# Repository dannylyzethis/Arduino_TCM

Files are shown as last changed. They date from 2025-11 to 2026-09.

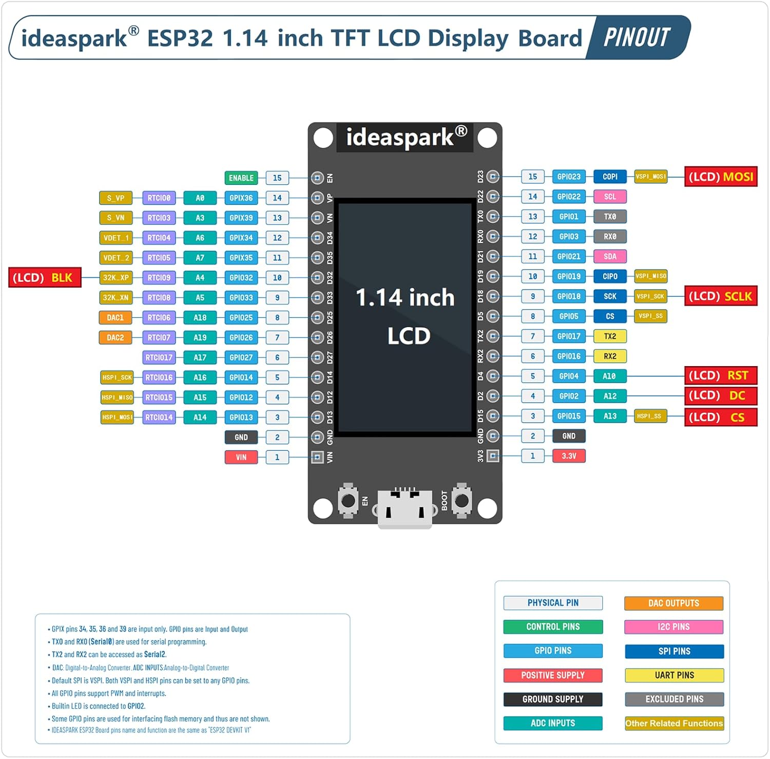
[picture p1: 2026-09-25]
hardware/references/ideaspark-pinout-source.jpg

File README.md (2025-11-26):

# Arduino TCM - Smart Home Climate Controller

Comprehensive home climate control system using ESP32 with:
- **Pellet Stove Control** (IR) - Automated temperature-based heat management
- **3 Ceiling Fans Control** (433MHz RF) - Independent fan speed and light control
- **Multi-Zone Temperature Monitoring** - DHT11 sensors with ESP-NOW wireless network
- **Temperature Equalization Learning** - AI learns to balance temps using fans
- **LCD Status Display** (Optional) - Real-time dashboard with all system status
- **Blynk IoT Integration** - Remote control from anywhere

## Features

### Pellet Stove Control (IR)
✅ **IR Learning Mode** - Capture commands from your pellet stove's remote
✅ **PID-Style Heat Control** - Automatically adjusts heat level (1-5) based on temperature
✅ **Manual Control** - Remote stove on/off and heat adjustment via Blynk app
✅ **Smart Heat Adjustment** - Uses 5 heat levels instead of on/off cycling
✅ **Adjustable Cooldown** - User-configurable interval (5-30 min) between auto adjustments
✅ **Heat Level Sync** - Manually sync software state with actual stove level

### Ceiling Fan Control (433MHz RF)
✅ **3 Independent Fans** - Control 3 separate ceiling fans
✅ **RF Learning Mode** - Capture commands from all 3 fan remotes
✅ **Speed Control** - Off, Low, Medium, High for each fan
✅ **Light Control** - Toggle lights on each fan
✅ **Persistent Storage** - RF codes saved to flash memory

### Temperature Equalization Learning
✅ **Automatic Learning** - System learns which fan affects which zone's temperature
✅ **Smart Fan Control** - Uses learned patterns to balance zone temperatures
✅ **Running Averages** - Collects up to 50 samples per fan/speed for accuracy
✅ **Auto-Equalization Mode** - Automatically balances temps when zones differ
✅ **Persistent Learning** - Learned patterns saved to flash memory

### General Features
✅ **Temperature & Humidity Monitoring** - Real-time DHT11 sensor readings
✅ **Multi-Zone Control** - Control stove based on temperature from different rooms
✅ **ESP-NOW Communication** - Fast, reliable wireless sensor network (no internet needed)
✅ **LCD Status Display** - Optional 135x240 color display shows all system status
✅ **Real-time Status** - Monitor all devices from anywhere via Blynk
✅ **Sensor Protection** - Auto-disables if temperature sensor fails
✅ **Unified Control** - Single Blynk app controls stove, fans, and monitors temperature

## Hardware Requirements

### Core Components
- **ESP32 development board**
- **DHT11** temperature and humidity sensor
- Jumper wires
- Breadboard

### For Pellet Stove Control (IR)
- **VS1838B** IR receiver module (38kHz)
- **940nm IR LED** transmitter
- **2N2222 NPN transistor** (for IR LED)
- **100Ω resistor** (for IR LED current limiting)
- **10kΩ resistor** (for transistor base)

### For Ceiling Fan Control (RF)
- **433MHz RF Transmitter Module** (FS1000A, SYN115, or RXB6)
- **433MHz RF Receiver Module** (Optional, for learning mode - RXB6 or WL101-341)
- **17cm wire antenna** (Optional, for better range)

### For LCD Display (Optional)
- **ST7789 LCD Display** (135x240 pixels) - Real-time status dashboard
- Display shows temperatures, fan status, heat level, learning progress

### Optional
- **Additional ESP32** with DHT11 for remote zone temperature monitoring
- Enclosure/case for permanent installation
- Power supply (USB or 5V adapter)

## Wiring Diagram

### DHT11 Temperature Sensor
```
DHT11          ESP32
─────────────────────
VCC     →      3.3V
GND     →      GND
DATA    →      GPIO13
```

### VS1838B IR Receiver
```
VS1838B        ESP32
─────────────────────
VCC     →      3.3V
GND     →      GND
OUT     →      GPIO14
```

### IR LED Transmitter Circuit
```
ESP32 GPIO5 ──┬─── 10kΩ ───┬─── Transistor Base (2N2222)
              │             │
             GND           Emitter → GND
                            │
                         Collector
                            │
                            ├─── IR LED Anode (+)
                            │
                          100Ω
                            │
                         5V/VIN

IR LED Cathode (-) → Transistor Collector
```

**Important Notes:**
- IR LED must be connected through a transistor (ESP32 GPIO can't provide enough current)
- Use 100Ω resistor to limit IR LED current (~40-50mA)
- Point IR LED directly at your pellet stove's IR receiver

### 433MHz RF Transmitter (Required for Fan Control)
```
RF TX Module   ESP32
─────────────────────
VCC     →      5V (or 3.3V depending on module)
GND     →      GND
DATA    →      GPIO16
ANT     →      17cm wire antenna (optional, for better range)
```

### 433MHz RF Receiver (Optional, for Learning Mode)
```
RF RX Module   ESP32
─────────────────────
VCC     →      5V (or 3.3V depending on module)
GND     →      GND
DATA    →      GPIO17
ANT     →      17cm wire antenna (optional, for better range)
```

**Important Notes:**
- Most RF modules work with both 3.3V and 5V, check your module's datasheet
- 17cm antenna wire significantly improves range (cut to exactly 17.3cm for 433MHz)
- RF transmitter is REQUIRED to control ceiling fans
- RF receiver is OPTIONAL - only needed for learning mode to capture fan remote codes
- If you already know your fan RF codes, you can skip the receiver and enter codes manually
- Point RF transmitter toward ceiling fans (RF works through walls, no line-of-sight needed)
- Typical range: 30-50 feet without antenna, 100+ feet with antenna

### ST7789 LCD Display (Optional, 135x240 pixels)
```
ST7789 LCD     ESP32
─────────────────────
VCC     →      3.3V
GND     →      GND
SCL     →      GPIO18 (SPI Clock / SCLK)
SDA     →      GPIO23 (SPI MOSI)
CS      →      GPIO15 (Chip Select)
DC      →      GPIO2  (Data/Command)
RST     →      GPIO4  (Reset)
BLK     →      GPIO32 (Backlight control)
```

**Display Features:**
- **Real-time Dashboard** - Updates every 2 seconds
- **Zone Temperatures** - Shows both Zone 1 and Zone 2 temperatures
- **Humidity Display** - Real-time humidity percentage
- **Heat Level Indicator** - Visual bar graph (1-5 blocks)
- **Fan Status** - Shows all 3 fans (OFF/LOW/MED/HI)
- **Learning Progress** - Total learning samples collected
- **Auto-Equalization Status** - Shows if auto-EQ is active
- **Temperature Difference** - Shows zone temp difference
- **WiFi/Blynk Status** - Connection indicators
- **Auto Mode Indicator** - Shows AUTO or MAN mode
- **Stove Status** - Shows ON/OFF state

**Display Layout (240x135 Landscape):**
```
┌────────────────────────────────────┐
│ STOVE CTRL          W B AUTO       │
│ Z1:72.5F  H:45%  Tgt:70F           │
│ Z2:70.2F  Heat:▓▓▓░░ ON            │
│ ────────────────────────            │
│ F1:HI  F2:OFF  F3:MED               │
│ Learn:23  AutoEQ:ON                 │
│ Diff:2.3F  Zone:1                   │
└────────────────────────────────────┘
```

## Software Requirements

### Arduino IDE Setup

1. Install [Arduino IDE](https://www.arduino.cc/en/software) (1.8.19 or later)
2. Add ESP32 board support:
   - Go to **File → Preferences**
   - Add to **Additional Board Manager URLs**:
     `https://dl.espressif.com/dl/package_esp32_index.json`
   - Go to **Tools → Board → Boards Manager**
   - Search for "ESP32" and install **"esp32 by Espressif Systems"**

### Required Libraries

Install via Arduino IDE (**Sketch → Include Library → Manage Libraries**):

| Library | Author | Purpose |
|---|---|---|
| **Blynk** | Volodymyr Shymanskyy | IoT platform connectivity |
| **DHT sensor library** | Adafruit | DHT11 temperature/humidity |
| **Adafruit Unified Sensor** | Adafruit | DHT library dependency |
| **IRremoteESP8266** | David Conran, Sebastien Warin | IR transmit/receive (pellet stove) |
| **rc-switch** | sui77 | 433MHz RF transmit/receive (ceiling fans) |
| **Adafruit GFX Library** | Adafruit | Graphics core for LCD (optional) |
| **Adafruit ST7789** | Adafruit | ST7789 LCD display driver (optional) |

## Blynk Setup

### 1. Create Blynk Project

1. Download [Blynk app](https://blynk.io/) (iOS/Android) or use [Blynk.Console](https://blynk.cloud/)
2. Create a new **Template** or **Project**
3. Note your **Template ID** and **Auth Token**

### 2. Add Datastreams

Configure these virtual pins in your Blynk template:

| Pin | Name | Type | Range | Purpose |
|-----|---|---|---|---|
| **V0** | Temperature | Value | 32-120°F | Current temperature display |
| **V2** | Humidity | Value | 0-100% | Current humidity display |
| **V3** | Stove ON | Button | 0-1 | Turn stove on |
| **V4** | Stove OFF | Button | 0-1 | Turn stove off |
| **V5** | Target Temp | Slider | 60-80°F | Temperature setpoint |
| **V6** | Auto Mode | Switch | 0-1 | Enable heat auto-adjustment |
| **V7** | Learn IR | Button | 0-1 | Enter learning mode |
| **V8** | Heat UP | Button | 0-1 | Manual heat increase |
| **V9** | Heat DOWN | Button | 0-1 | Manual heat decrease |
| **V10** | Heat Level | Value | 0-5 | Current heat level display |
| **V11** | Stove Status | LED/Value | 0-1 | Stove on/off indicator |
| **V12** | Cooldown Period | Slider | 5-30 min | Auto adjustment interval |
| **V13** | Heat Sync | Slider | 0-5 | Manual heat level sync |
| **V14** | Zone Select | Menu | 0-2 | Select active zone (0=Zone1, 1=Zone2, 2=Avg) |
| **V15** | Zone 2 Temp | Value | 32-120°F | Remote sensor temperature |

### 3. Add Dashboard Widgets

**Recommended Dashboard Layout:**
- **Gauge** widget → V0 (Temperature in °F)
- **Gauge** widget → V2 (Humidity %)
- **Button** widget → V3 (Stove ON)
- **Button** widget → V4 (Stove OFF)
- **Slider** widget → V5 (Target Temperature: 60-80°F)
- **Switch** widget → V6 (Auto Mode)
- **Button** widget → V7 (Learn IR Codes)
- **Button** widget → V8 (Heat UP ↑)
- **Button** widget → V9 (Heat DOWN ↓)
- **Value Display** widget → V10 (Heat Level: 0-5)
- **LED** widget → V11 (Stove Status: On/Off)
- **Slider** widget → V12 (Cooldown Period: 5-30 minutes)
- **Slider** widget → V13 (Heat Level Sync: 0-5)
- **Menu** widget → V14 (Zone Select: Zone 1, Zone 2, Average)
- **Value Display** widget → V15 (Zone 2 Temperature)

## Configuration

### Update Credentials

Edit `Arduino_TCM_Blynk_DHT11.ino` with your details:

```cpp
// Blynk credentials
#define BLYNK_TEMPLATE_ID "YOUR_TEMPLATE_ID"
char auth[] = "YOUR_AUTH_TOKEN";

// WiFi credentials
char ssid[] = "YOUR_WIFI_SSID";
char pass[] = "YOUR_WIFI_PASSWORD";
```

### Adjust Pin Assignments (if needed)

```cpp
#define DHTPIN 4        // DHT11 sensor data pin
#define IR_RECV_PIN 14  // IR receiver output
#define IR_SEND_PIN 15  // IR LED control pin
```

### Set Temperature Preferences

```cpp
float tempSetpoint = 70.0;          // Default target temperature (°F)
float tempHysteresis = 2.0;         // Temperature buffer for heat adjustments
unsigned long adjustmentCooldown = 900000; // 15 minutes between adjustments (ms)
```

**How PID-Style Control Works:**
- Stove stays **ON** (you control on/off manually)
- Heat level **increases** when temp < `setpoint - 2°F` (e.g., < 68°F)
- Heat level **decreases** when temp > `setpoint + 2°F` (e.g., > 72°F)
- Adjustments happen at configurable intervals (default: 15 minutes)
- Cooldown period can be adjusted via Blynk slider (5-30 minutes)
- Heat levels range from 1 (minimum) to 5 (maximum)

## Installation & Setup

### Step 1: Upload Code

1. Open `Arduino_TCM_Blynk_DHT11/Arduino_TCM_Blynk_DHT11.ino` in Arduino IDE
2. Update credentials (see Configuration section)
3. Select board: **Tools → Board → ESP32 Arduino → ESP32 Dev Module**
4. Select COM port: **Tools → Port → (your port)**
5. Click **Upload** ⬆️
6. Open **Serial Monitor** (115200 baud) to verify connection

### Step 2: Learn IR Codes

**You must teach the system your pellet stove's remote commands:**

1. In **Blynk app**, tap the **"Learn IR"** button (V7)
2. Watch the **Serial Monitor** for instructions
3. When prompted, press these buttons on your **pellet stove remote**:
   - **POWER ON** button (point remote at VS1838B receiver)
   - Wait for confirmation ✓
   - **POWER OFF** button
   - Wait for confirmation ✓
   - **HEAT UP** button
   - Wait for confirmation ✓
   - **HEAT DOWN** button
   - Wait for confirmation ✓

4. Serial Monitor will display captured codes:
   ```
   === IR CODES SAVED ===
   Power ON: 0x1234ABCD
   Power OFF: 0x5678EF01
   Heat Up: 0x9ABC2345
   Heat Down: 0xDEF67890
   Learning mode complete!
   ```

5. **Codes are automatically saved to flash memory!**
   - IR codes persist through power cycles and reboots
   - No need to re-learn codes after restarting
   - Codes are loaded automatically on startup

**Note:** If you want to re-learn codes, just press the "Learn IR" button again - new codes will overwrite the old ones.

### Step 3: Test Manual Control

1. In Blynk app, tap **"Stove ON"** button (V3)
2. Watch your pellet stove turn on (starts at heat level 3)
3. Check **Stove Status** LED (V11) turns on
4. Check **Heat Level** display (V10) shows "3"
5. Test **Heat UP** (V8) and **Heat DOWN** (V9) buttons
6. Verify heat level changes (should range 1-5)
7. Test **"Stove OFF"** button (V4) to turn off

### Step 4: Enable Heat Automation

1. **Turn stove ON** manually using V3 button
2. Set desired **Target Temperature** using slider (V5) - e.g., 70°F
3. **Optional:** Adjust **Cooldown Period** slider (V12) - default is 15 minutes
4. Enable **Auto Mode** switch (V6)
5. System will automatically adjust heat level at your chosen interval:
   - **Increase heat** when temp < 68°F (up to level 5)
   - **Decrease heat** when temp > 72°F (down to level 1)
   - **Maintain** heat level when temp is 68-72°F

### Step 5: Sync Heat Level (If Needed)

If the system's heat level gets out of sync with your actual stove (e.g., after a reboot or manual remote changes):

1. Check your stove's actual heat level (look at the display)
2. Use **Heat Sync slider** (V13) to set the correct level (0-5)
3. System now knows the true stove state
4. Auto mode will work correctly from this point

**When to use:**
- After ESP32 reboots while stove is running
- If you manually changed heat using the physical remote
- If an IR command failed and states are mismatched

### Step 6: Setup Multi-Zone Control (Optional)

Control your pellet stove based on temperature from a different room using ESP-NOW wireless communication.

**What You Need:**
- Second ESP32 board
- DHT11 sensor for remote room
- 5V power supply for remote sensor

**Setup Instructions:**

1. **Get Main Controller's MAC Address**
   - Upload main sketch to primary ESP32
   - Open Serial Monitor (115200 baud)
   - Look for MAC address in WiFi connection messages
   - Note it down (format: XX:XX:XX:XX:XX:XX)

2. **Program Remote Sensor**
   - Open `Remote_Sensor_ESP32/Remote_Sensor_ESP32.ino`
   - Replace `mainControllerMAC[]` with your main controller's MAC
   - Update WiFi credentials (must match main controller)
   - Upload to second ESP32

3. **Wire Remote Sensor**
   ```
   DHT11          ESP32
   ─────────────────────
   VCC     →      3.3V
   GND     →      GND
   DATA    →      GPIO4
   ```

4. **Place Remote Sensor**
   - Install in room you want to monitor
   - Must be within WiFi range of main controller
   - Sends temperature every 30 seconds

5. **Configure Zone in Blynk App**
   - Use **Zone Select menu** (V14):
     - **Zone 1** - Control based on stove room temp (local sensor)
     - **Zone 2** - Control based on remote room temp
     - **Average** - Use average of both rooms
   - View **Zone 2 Temp** (V15) to verify remote sensor is working

**How It Works:**
- Remote sensor sends temp via ESP-NOW (no internet needed)
- Main controller receives and displays on V15
- Select which zone controls the stove via V14
- Auto mode adjusts heat based on selected zone

**Troubleshooting:**
- If Zone 2 shows 0°F → Check MAC address configuration
- If "Remote sensor offline" → Check WiFi connection and range
- System automatically falls back to Zone 1 if remote fails

## Usage

### Manual Mode (Default)
- Use **Stove ON** (V3) and **Stove OFF** (V4) buttons to control power
- Use **Heat UP** (V8) and **Heat DOWN** (V9) to manually adjust heat (1-5)
- Monitor temperature, humidity, and current heat level in real-time
- Full manual control without any automation

### Auto Mode (Smart Heat Adjustment)
1. **Turn stove ON** manually first (V3)
2. Set target temperature with slider (V5)
3. Adjust cooldown period with slider (V12) - default 15 min, range 5-30 min
4. Enable Auto Mode switch (V6)
5. System automatically adjusts heat level at your chosen interval:
   - Too cold → Increases heat (up to level 5)
   - Too hot → Decreases heat (down to level 1)
   - Just right → Maintains current heat level
6. Can adjust cooldown period anytime (even while auto mode is running)
7. Can still manually adjust heat or turn off stove anytime
8. Auto mode disables when you turn stove OFF

### Monitoring
- **Temperature** updates every 2 minutes
- **Humidity** updates every 2 minutes
- **Heat level** (1-5) displays current setting
- **Stove status** LED shows on/off state
- Serial Monitor provides detailed automation logs

## How It Works

### PID-Style Heat Level Control

Unlike simple on/off thermostats, this system uses **proportional control** by adjusting heat levels:

```
Current Temp < Target - 2°F  →  Increase heat level (1→2→3→4→5)
Current Temp > Target + 2°F  →  Decrease heat level (5→4→3→2→1)
Within ±2°F of target       →  Maintain current heat level
```

**Example (Target = 70°F, Cooldown = 15 min):**
- Room at 65°F, Heat Level 2 → **Increases to Level 3** (15 min later)
- Room at 67°F, Heat Level 3 → **Increases to Level 4** (15 min later)
- Room at 69°F, Heat Level 4 → **Maintains Level 4** (in range)
- Room reaches 72°F → **Decreases to Level 3** (15 min later)
- System continuously adjusts to maintain comfort

**Why This is Better:**
- Pellet stoves are designed for continuous operation, not on/off cycling
- Smoother temperature control without temperature swings
- More efficient fuel usage
- Extends stove lifespan (less wear from start/stop cycles)

### Safety Features

- **Manual on/off control** - You control when stove turns on/off (not automated)
- **Sensor failure protection** - Auto mode disables after 3 consecutive sensor failures
- **IR code validation** - Won't send commands if codes not learned
- **Heat level limits** - Won't exceed min (1) or max (5) settings
- **Adjustable cooldown** - User-configurable intervals (5-30 min) prevent command spam
- **Manual override** - Can disable auto mode or adjust heat anytime
- **Auto-disable on OFF** - Auto mode turns off when stove is manually shut off
- **Persistent storage** - IR codes survive power outages and reboots

## Troubleshooting

### DHT11 Sensor Issues

**Symptom:** "Failed to read from DHT sensor!"

**Solutions:**
- ✓ Check wiring (VCC, GND, DATA)
- ✓ Ensure sensor has power (3.3V or 5V)
- ✓ Verify `DHTPIN` matches GPIO4
- ✓ Try adding 10kΩ pull-up resistor on data line

### IR Learning Fails

**Symptom:** No codes captured / "IR Signal Received!" not appearing

**Solutions:**
- ✓ Check VS1838B wiring (VCC, GND, OUT)
- ✓ Point remote **directly** at receiver (2-6 inches away)
- ✓ Replace remote batteries
- ✓ Verify receiver pin is GPIO14
- ✓ Check Serial Monitor is open (115200 baud)

### IR Commands Not Working

**Symptom:** Stove doesn't respond to commands

**Solutions:**
- ✓ Check IR LED wiring and transistor circuit
- ✓ Verify 100Ω resistor in series with IR LED
- ✓ Point IR LED directly at stove's receiver
- ✓ Reduce distance (try 1-3 feet initially)
- ✓ Check LED polarity (long leg = anode/+)
- ✓ Some stoves use different protocols - try adjusting:
  ```cpp
  irsend.sendNEC(code, 32);  // Try: sendSony, sendRC5, sendSamsung
  ```

### WiFi Connection Issues

**Symptom:** Can't connect to WiFi

**Solutions:**
- ✓ Verify SSID and password are correct
- ✓ ESP32 only supports **2.4GHz** networks (not 5GHz)
- ✓ Check WiFi signal strength
- ✓ Restart router if necessary

### Blynk Connection Issues

**Symptom:** "Not connected to Blynk"

**Solutions:**
- ✓ Verify Auth Token is correct (copy from Blynk.Console)
- ✓ Check Template ID matches
- ✓ Ensure virtual pins match datastream configuration
- ✓ Check Blynk server status at [status.blynk.cc](https://status.blynk.cc)

### Automation Not Adjusting Heat

**Symptom:** Auto mode enabled but heat level doesn't change

**Solutions:**
- ✓ **Stove must be ON** - Auto mode only works when stove is running
- ✓ Verify IR codes were learned successfully (Power, Heat Up, Heat Down)
- ✓ Check temperature is outside hysteresis range (±2°F)
- ✓ **Wait for cooldown period** - default is 15 minutes between adjustments
- ✓ Check Cooldown Period slider (V12) - may be set too high
- ✓ Ensure Auto Mode switch (V6) is ON
- ✓ Monitor Serial output for automation messages
- ✓ Check Heat Level display (V10) - should be 1-5
- ✓ Manually test Heat UP/DOWN buttons first
- ✓ If at max heat (5) and still cold, system won't increase further
- ✓ If at min heat (1) and still hot, system won't decrease further

## Advanced Customization

### Change Update Frequency

```cpp
// Default: 2 minutes (120,000 ms)
timer.setInterval(120000L, sendData);

// Change to 1 minute:
timer.setInterval(60000L, sendData);
```

### Adjust Temperature Control Parameters

```cpp
// Default: ±2°F buffer before adjusting heat
float tempHysteresis = 2.0;

// Tighter control (±1°F) - more frequent adjustments:
float tempHysteresis = 1.0;

// Wider buffer (±3°F) - less frequent adjustments:
float tempHysteresis = 3.0;

// Adjustment cooldown (default: 15 minutes)
unsigned long adjustmentCooldown = 900000; // milliseconds

// Note: Cooldown can also be adjusted via Blynk slider (V12)
// Range: 5-30 minutes (300000-1800000 ms)
```

**Recommended Cooldown Settings:**
- **5-10 minutes** - Quick response, smaller spaces, well-insulated
- **15 minutes** - Default, balanced for most pellet stoves
- **20-30 minutes** - Conservative, larger spaces, slow-response stoves

### Add More IR Commands

```cpp
// In setup, learn additional buttons:
uint64_t irCode_FanSpeed = 0;
uint64_t irCode_Timer = 0;

// Create new Blynk handlers:
BLYNK_WRITE(V8) {
  if (param.asInt() == 1) {
    sendIRCommand(irCode_FanSpeed);
  }
}
```

### Change IR Protocol

If your stove uses a different IR protocol, modify:

```cpp
// Line 70 - Change from NEC to your protocol:
irsend.sendSony(code, 12);      // Sony 12-bit
// or
irsend.sendRC5(code, 13);       // RC5
// or
irsend.sendSamsung(code, 32);   // Samsung
```

## Safety Disclaimer

⚠️ **IMPORTANT SAFETY INFORMATION** ⚠️

This is an automation project for educational purposes. When using with heating appliances:

- **Never leave automated stove unattended for extended periods**
- **Install smoke detectors and CO detectors near stove**
- **Ensure stove has proper clearances from combustible materials**
- **Follow all manufacturer safety guidelines**
- **Use at your own risk** - author assumes no liability
- **Test thoroughly** before relying on automation
- **Manual override should always be accessible**

## Project Structure

```
Arduino_TCM/
├── Arduino_TCM_Blynk_DHT11/
│   └── Arduino_TCM_Blynk_DHT11.ino    # Main controller sketch
├── Remote_Sensor_ESP32/
│   └── Remote_Sensor_ESP32.ino        # Remote zone sensor (optional)
└── README.md                           # This file
```

## Future Enhancements

Potential additions (contributions welcome!):
- [ ] EEPROM storage for learned IR codes (persist across reboots)
- [ ] Weekly temperature schedule
- [ ] Multiple temperature zones
- [ ] Push notifications (low temp alerts)
- [ ] Historical data logging
- [ ] Web dashboard
- [ ] Voice control integration (Alexa/Google Home)

## License

Open source - MIT License. Free to modify and use for personal projects.

## Support

For issues or questions:
- Check troubleshooting section above
- Review serial monitor output for debugging
- Verify all wiring matches diagrams
- Test components individually

---

**Built with:** ESP32 | DHT11 | VS1838B | IR LED | Blynk IoT
**Author:** Arduino TCM Project
**Version:** 2.1 (PID-style heat level control)

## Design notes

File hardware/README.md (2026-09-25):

# Arduino TCM board design — Rev A planning

Status: native KiCad electrical draft created; physical socket and RF details remain unverified. No PCB or fabrication files.
Firmware baseline: commit 651ab30, Arduino_TCM_Blynk_DHT11.ino.

Circuit work: see [shared node circuit draft](node-circuit-draft.md) and `node-circuit-model.json` for proposed component values, connectivity, GPIO assignments and stove/fan assembly variants. These supersede the early connector concepts below. Native schematic: `tcm_node_rev_a_draft.kicad_sch`; project: `tcm_node_rev_a_draft.kicad_pro`. The repository now resides in C:/Projects/Arduino_TCM. Initial ERC passed with zero errors and warnings; the exported connections matched the design model. See preview/ for SVG and PNG views. This does not validate real hardware compatibility.

## Scope and decisions

Accepted architecture: one ELECROW CrowPanel Basic 7-inch dashboard/coordinator, one independent stove-control node, and three fan nodes. Five ESP32 devices total. The user selected independent stove control so a dashboard restart or update does not itself stop the stove node's local control loop. Fan nodes transmit RF commands; the stove node transmits IR commands. No wired appliance-power switching is required.

Working PCB direction: one common carrier PCB with different component population for stove and fan roles. Plug-in ESP32 development boards remain the working preference; exact model and mechanical fit are pending. The CrowPanel already includes its own ESP32 and does not require this carrier to operate its display.

| Role | Quantity | Planned peripherals |
| --- | ---: | --- |
| CrowPanel dashboard | 1 | Built-in display/touch and ESP32; user settings, zone overview and wireless coordination |
| Stove node | 1 | Local temperature sensor, IR emitter/receiver; independent local control |
| Fan node | 3 | Local temperature sensor, RF transmitter, optional RF learning receiver; wireless command/telemetry link |

The existing firmware transmits all fan commands from the main controller, and the remote sketch is a sensor node. Distributed fan control therefore requires firmware changes: addressed commands, node registration, acknowledgements, duplicate suppression, freshness limits, local code storage and explicit lost-link behavior. ESP-NOW is the provisional inter-board transport because the repository already uses it. Channel coordination with the main controller's Wi-Fi connection must be designed and tested.

An acknowledgement from a fan node confirms command handling/transmission, not physical fan operation. RF toggle commands, especially light toggles, must not be re-executed on network retries. Keep desired state and last transmitted state distinct from any independently confirmed state.

RF frequency, modulation and protocol are unverified. The repository assumes 433 MHz and uses RCSwitch; do not select a production RF module from that assumption alone. Obtain each remote's model/FCC ID or manufacturer documentation and verify capture/replay compatibility. Nearby placement does not isolate fans that share the same RF address; pairing/address behavior must also be tested.

Exact node ESP32 and RF module models, sensor choice, input supply, enclosure dimensions and assembly preference must be selected before footprints and board outline are finalized. Do not assume different ESP32 development boards share header spacing or pin order. Confirm the CrowPanel model and PCB revision against ELECROW documentation before firmware bring-up; the Amazon listing title alone does not establish the revision.

## Control responsibilities

### Node board candidate and power decision

All four custom nodes will use USB wall adapters (confirmed by user). The nominated plug-in board is the ideaspark ESP32 development board with integrated 1.14-inch ST7789 135x240 display, CH340 USB serial, USB-C and soldered headers, as described in the user's listing title. Treat it as the current candidate, pending verified header pinout, row spacing, outline, underside clearance and power schematic. Do not substitute a generic ESP32 DevKit footprint.

The local display can show node identity, temperature, connection health and last transmitted command. The existing repository already targets an ST7789 at this resolution, but this does not establish electrical compatibility or successful operation on the candidate board. Preserve integrated display wiring; any earlier suggestion to move LCD CS/DC applies only to separately wired displays, not fixed PCB connections. Reserve firmware LCD GPIOs 23, 18, 15, 2, 4 and 32 provisionally until the actual board pinout is verified.

Keep the USB connector and screen accessible when placing the carrier sockets. Determine how peripheral power is drawn from USB without overloading the onboard regulator or creating a second power path. RF module supply and connector remain unresolved until remote identification; leave the RF module interface modular in the architecture, not a finalized footprint.

Candidate listing supplied by user: https://a.co/d/050E23FP . No mechanical drawing or manufacturer schematic has yet been verified.

### Firmware ownership

- Dashboard: present room measurements and node health, send settings and manual requests, coordinate fan behavior, and optionally provide the Blynk bridge.
- Stove node: own IR timing, learned codes, heat-adjustment cooldown and the local control loop. Dashboard requests pass through the node's control logic. Define startup behavior, sensor-fault behavior and loss of remote-temperature data before enabling automation.
- Fan nodes: own RF transmission and learned codes; report local temperature and command acknowledgements. Define loss-of-link behavior explicitly rather than assuming an automatic off command is appropriate.
- All nodes: report measurement age, fault state and last applied command ID. Reject stale requests and suppress duplicate actions. A screen restart must not replay an old power/light toggle.
- Autonomous stove operation is a design objective, not a claim of implemented behavior. Persistence, restart handling and fallback from a stale remote zone still require implementation and bench validation.

## Functional architecture

```mermaid
flowchart LR
  H[CrowPanel dashboard / coordinator] <-. Proposed ESP-NOW link .-> S[Independent stove node]
  H <-. Proposed ESP-NOW link .-> N[Fan nodes x3]
  ST[Stove-zone temperature sensor] --> S
  IR[IR learning receiver] --> S
  S --> DRIVER[IR LED driver and emitter]
  DRIVER -. IR commands .-> STOVE[Pellet stove]
  T[Local temperature sensor per node] --> N
  N --> TX[RF transmitter per node]
  RX[Optional RF learning receiver per node] --> N
  TX -. Fan remote protocol .-> F[Respective ceiling fan]
```

## Firmware pin inventory

These are GPIO numbers, not module pad numbers or development-board header positions. This inventory describes the existing centralized firmware; the fan-node pin map remains to be finalized.

| Function | Existing GPIO | Board-design consideration |
| --- | ---: | --- |
| DHT data | 13 | Pull-up to the selected sensor-compatible logic rail; verify exact sensor supply specification |
| IR receiver output | 14 | Verify receiver supply, output levels and physical pin order |
| IR transmitter control | 5 | Boot-strapping pin; proposed reassignment to GPIO25 if the chosen ESP32 supports it |
| RF transmitter data | 16 | Confirm availability on exact ESP32 variant and transmitter input threshold |
| RF receiver data | 17 | Confirm availability and receiver output voltage; translate levels if needed |
| LCD MOSI | 23 | Verify display connector pin order |
| LCD SCLK | 18 | Keep SPI connections short |
| LCD CS | 15 | Preserve integrated display wiring; do not load with carrier circuitry |
| LCD DC | 2 | Preserve integrated display wiring; do not load with carrier circuitry |
| LCD reset | 4 | Retain provisionally |
| LCD backlight enable | 32 | Verify whether module pin is a logic input or requires a current driver |

The proposed changes apply provisionally to a classic ESP32 with those pins available. They have not been applied to firmware. GPIO16/17 availability must be checked against the chosen module, including any PSRAM usage.

## Proposed connector functions

Pin order and connector part numbers are intentionally pending the actual hardware.

| Reference | Interface | Signals / requirements |
| --- | --- | --- |
| J1 | Power input | Supply and ground; input voltage and connector TBD |
| J2 | Local sensor | Sensor supply, ground, DHT data; short external cable allows separation from board heat |
| J3 | IR emitter | Current-limited LED supply and switched return; polarity marked |
| J4 | IR receiver | Selected receiver supply, ground, data |
| J5 | RF transmitter | Selected module supply, ground, data; antenna arrangement per module |
| J6 | RF receiver | Selected module supply, ground, level-compatible data |
| J7 | Reserved | No separate LCD connector required; display is on the CrowPanel |
| J8 | Programming/service | Defined after MCU choice; integrated module needs UART/reset/boot provision |

## Electrical work before schematic freeze

- Build separate power budgets for the CrowPanel and each node, covering radio transients and RF/IR loads. Espressif specifies at least 500 mA supply capability for the classic ESP32 itself; this is not a complete node budget. All four nodes use USB wall adapters; exact adapter rating and available peripheral current remain to be verified.
- If using a development board, verify its regulator capacity and USB/external-power path. Prevent backfeeding when programming with another supply attached.
- If using an integrated module, implement its specified supply decoupling, enable/reset timing, boot control, programming interface and antenna keepout.
- Correct the README's ambiguous IR circuit: supply -> current-limiting resistor -> LED anode; LED cathode -> transistor collector/drain; emitter/source -> ground. Select a transistor driven correctly at 3.3 V, a default-off control network, and resistor ratings from the actual LED pulse limits and duty cycle. Do not copy the existing drawing or its resistor values without calculation.
- Verify every peripheral's supply and logic limits. A module powered at 5 V must not automatically be treated as safe for a 3.3 V ESP32 input.
- Verify sensor voltage requirements from its manufacturer; module pull-ups may connect data to its supply rail.
- Use the CrowPanel's onboard display/backlight circuitry and revision-specific drivers. The legacy ST7789 pin map is not the CrowPanel pin map.
- Provide test points for input supply, 3.3 V, ground and key control signals. Keep IR pulse-current return paths away from receiver and sensor circuitry.
- Place ESP32 antenna at a suitable edge with the exact module's specified keepout. Keep regulator/processor heat away from the temperature sensor.

## Next deliverables

1. Confirm exact modules, supply and mechanical constraints.
2. Select component part numbers and datasheets, then draw a native KiCad schematic and resolve electrical-rule findings.
3. Assign verified footprints; place connectors and mounting holes against the enclosure.
4. Route the PCB, check schematic parity and design rules, and inspect fabrication previews.
5. Bring up power first, then programming/boot, sensors, display, RF and IR. Test cold boot and reset with every peripheral connected.

## References

- Existing firmware: ../Arduino_TCM_Blynk_DHT11/Arduino_TCM_Blynk_DHT11.ino
- Espressif schematic checklist: https://docs.espressif.com/projects/esp-hardware-design-guidelines/en/latest/esp32/schematic-checklist.html
- ESP32 datasheet: https://documentation.espressif.com/esp32_datasheet_en.html
- ESP32 hardware design guidelines: https://documentation.espressif.com/esp-hardware-design-guidelines/en/latest/esp32/index.html
- CrowPanel Basic 7-inch documentation: https://www.elecrow.com/wiki/esp32-display-702727-intelligent-touch-screen-wi-fi26ble-800480-hmi-display.html

## A1 socket mapping

J1 and J8 now represent the two 15-position ideaspark header rows, mapped from the original product pinout image. See [socket map](ideaspark-socket-map.md). The A0 logical port is superseded. Mechanical spacing and the USB/VIN power path remain unresolved.

## A2 discrete footprints and assembly plan

Fourteen discrete components now have library footprints: 0805 small resistors and bypass capacitors, 2010 IR current resistor, 1210 bulk capacitors, and SOT-23-3 MOSFET. Eight connector footprints remain pending. See [parts and assembly plan](parts-and-assembly.md). ERC and netlist results are recorded in validation/. No PCB or manufacturing release is produced.

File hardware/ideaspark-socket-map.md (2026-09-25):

# Ideaspark socket mapping - A1

Source: original ideaspark-branded product pinout graphic, visually inspected. Local copy: [pinout](references/ideaspark-pinout-source.jpg).

Original image: https://m.media-amazon.com/images/I/71j0W0VM6CL._AC_SL1500_.jpg

View: screen facing viewer, USB connector at bottom. J1 is the left row; J8 is the right row. Pin 1 is nearest USB on both rows. These are separate 15-position sockets, not a consecutively numbered 30-pin connector. Pin numbering in the drawing runs bottom-to-top. Carrier footprint orientation must preserve this view and must not mirror the underside accidentally.

| Pin | J1 left | J8 right |
| --- | --- | --- |
| 1 | VIN | 3V3 |
| 2 | GND | GND |
| 3 | GPIO13 | GPIO15 (LCD CS) |
| 4 | GPIO12 | GPIO2 (LCD DC) |
| 5 | GPIO14 | GPIO4 (LCD reset) |
| 6 | GPIO27 | GPIO16 |
| 7 | GPIO26 | GPIO17 |
| 8 | GPIO25 | GPIO5 |
| 9 | GPIO33 | GPIO18 (LCD clock) |
| 10 | GPIO32 (LCD backlight) | GPIO19 |
| 11 | GPIO35 | GPIO21 |
| 12 | GPIO34 | GPIO3 (USB serial RX) |
| 13 | GPIO39 | GPIO1 (USB serial TX) |
| 14 | GPIO36 | GPIO22 |
| 15 | EN | GPIO23 (LCD MOSI) |

Unused socket contacts carry no-connect markers on the carrier only. This does not disconnect the display or USB bridge already wired on the ideaspark board. Both ground contacts are connected.

The product graphic establishes pin count, order and GPIO labels, but does not specify header-row spacing or pin pitch numerically. No socket footprint or row-spacing value is frozen. VIN is a label, not proof that it provides USB 5 V output: the USB-to-VIN power path and current capacity still require verification before powering the IR emitter from it.

The source webpage transcription incorrectly associated GPIO21 with backlight; the original product graphic explicitly places LCD backlight on GPIO32. The schematic follows the product graphic.

A1 supersedes the A0 logical 14-pin connector. The complete GPIO-to-socket mapping is now recorded in the native schematic and model.

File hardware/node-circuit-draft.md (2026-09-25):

# Shared node circuit — A0

Electrical proposal, not a fabrication release. Native KiCad schematic and project are now generated in this directory. ERC passed with zero errors and warnings, and the exported netlist matched all model connections. Socket pin mapping is documented from the product graphic. Socket geometry, connector footprints, power capability and RF compatibility remain unverified. The model uses passive logical interfaces, so ERC cannot prove external-module electrical compatibility. Preview files are in preview/. Cosmetic text placement was adjusted after generation; regenerating from the model may require repeating that visual cleanup.

## Common circuitry

Use the user's ideaspark ESP32/ST7789 board in sockets. Power each node through its existing USB port from a wall adapter. Take peripheral power only from verified 5 V and 3.3 V header connections after checking the board's USB path and regulator capacity. No second power input is included in this draft.

Provide 100 nF plus 10 uF local bypass capacitors on the carrier's 3.3 V rail. These are provisional starting values; component tolerances and USB startup/inrush need review. Reserve all display signals. The carrier has no additional display connector.

The A1 schematic uses two physical 15-position socket symbols: J1 (left) and J8 (right). See [socket mapping](ideaspark-socket-map.md) for the original product graphic, viewing orientation and all 30 contact assignments. The earlier A0 logical 14-pin connector has been replaced. GPIO25 remains the proposed IR output; display GPIO23/18/15/2/4/32 remain reserved. Socket footprints and header-row spacing are not yet frozen.

## Sensor options

J2 provides 3.3 V, GND, SDA and SCL for a short-cable I2C sensor module. Optional 4.7 kohm pull-ups are not populated if the module already provides suitable pull-ups. J3 provides a separate 3.3 V/GND/data interface with an optional pull-up for a compatible single-data-wire sensor. Select the actual sensor before assembly; this is not a claim that every DHT11 variant is specified for 3.3 V. Keep the sensor away from processor/display heat and direct stove radiant heat when measuring room temperature.

## Stove population: IR transmitter

Circuit: verified USB 5 V -> R3 -> J4 pin 1 -> external LED anode; external LED cathode -> J4 pin 2 -> Q1 drain; Q1 source -> GND.

- Q1: AO3400A N-channel MOSFET candidate; gate=1, source=2, drain=3. Manufacturer specifies on-resistance at 2.5 V gate drive, supporting this 3.3 V logic application.
- R1: 100 ohm series gate resistor from GPIO25.
- R2: 100 kohm gate-to-ground resistor for default-off behavior during reset.
- R3: 100 ohm, 1%, 0.5 W initial LED current limit.
- External emitter candidate: Vishay TSAL6200, 940 nm. Connector polarity must be marked.
- C4/C5: 10 uF and 100 nF near the IR supply branch; route pulse-current return directly toward supply ground.

Initial estimate at 5 V with approximately 1.3 V LED drop: (5 - 1.3)/100 = 37 mA while on. This is an estimate, not a guaranteed current. At an assumed 5.25 V maximum source and 99 ohm minimum resistance, even a shorted LED limits resistor dissipation to 5.25^2/99 = 0.278 W before considering supply-path resistance; 0.5 W is the starting rating, subject to package and ambient derating. Do not increase current until LED thermal/pulse limits, driver waveform, power budget and required range are tested.

J5 provides 3.3 V/GND/receiver output with local 100 nF decoupling. The actual receiver part, carrier frequency and filtering are pending stove-remote verification. Do not assume all 3-pin receivers share pin order. The connector describes our cable contract, not a bare receiver package.

## Fan population: RF adapter

J6 is an eight-signal adapter contract, not a ready-to-plug radio footprint: 3.3 V, GND, TX-data/CS, RX-data/IRQ, SCLK, MOSI, MISO, AUX. It leaves room for simple data-controlled modules or an SPI radio, depending on the actual remote protocol. All signals must remain ESP32-compatible 3.3 V logic. Any voltage conversion belongs in the selected adapter design.

R8 is a 100 kohm pull-down for a simple active-high RF transmitter's data input only. Omit it for an SPI adapter, which needs its own correct CS/reset biasing. No universal radio biasing is assumed.

J7 optionally exposes 5 V and GND to the adapter through R7, a normally-unpopulated zero-ohm link. Populate only after confirming the radio power requirement and USB current budget. This is not a power input. Do not short this rail to the 3.3 V radio supply.

RF frequency, modulation, addressing and code format remain unknown. The existing 433 MHz/RCSwitch code does not prove compatibility. No RF module, antenna or adapter connector footprint is selected yet.

## Assembly variants

| Circuit | Stove node | Fan node |
| --- | --- | --- |
| Socketed ideaspark, local display, sensor and rail decoupling | Fit | Fit |
| Q1, R1-R3, J4/J5, C3-C5 | Fit | Omit |
| J6 RF interface | Omit | Fit after module selection |
| R8 simple-TX pull-down | Omit | Conditional |
| R7/J7 5 V RF branch | Omit | Conditional, normally omitted |

## Remaining validation

Confirm board header mapping and dimensions, verify available current, select sensor and receiver, identify fan RF protocol, assign connector parts/footprints, generate and inspect the native schematic, run ERC, and then place/route the carrier. Initial bench work should exercise transmission capture and node communication before controlling appliances.

## Sources

- AO3400A manufacturer datasheet: https://aosmd.com/res/data_sheets/AO3400A.pdf
- TSAL6200 manufacturer datasheet: https://www.vishay.com/docs/81010/tsal6200.pdf
- Board-linked display example: https://github.com/GJKJ/ESP32114LCD

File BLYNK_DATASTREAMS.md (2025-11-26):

# Blynk Datastreams Configuration

Complete datastream definitions for Arduino TCM Smart Home Climate Controller.

---

## Datastream Table (CSV Format)

```csv
Pin,Name,Data Type,Min,Max,Default,Unit,Direction,Description
V0,Local Temperature,Double,0,120,70,°F,Read,Local DHT11 temperature sensor (Zone 0 - Main/Stove area)
V2,Local Humidity,Integer,0,100,50,%,Read,Local DHT11 humidity sensor
V3,Stove Power ON,Integer,0,1,0,,Write,Button to turn pellet stove ON
V4,Stove Power OFF,Integer,0,1,0,,Write,Button to turn pellet stove OFF
V5,Target Temperature,Double,60,80,70,°F,Write,Temperature setpoint for auto mode
V6,Auto Mode,Integer,0,1,0,,Read/Write,Enable/disable automatic temperature control
V7,IR Learning Mode,Integer,0,1,0,,Write,Activate IR code learning mode for stove remote
V8,Heat Level UP,Integer,0,1,0,,Write,Manually increase heat level (+1)
V9,Heat Level DOWN,Integer,0,1,0,,Write,Manually decrease heat level (-1)
V10,Current Heat Level,Integer,0,5,0,,Read,Current stove heat setting (0=OFF 1-5=heat levels)
V11,Stove Status,Integer,0,1,0,,Read,Stove power status (0=OFF 1=ON)
V12,Adjustment Cooldown,Integer,5,30,15,min,Write,Cooldown period between auto adjustments
V13,Manual Heat Sync,Integer,0,5,3,,Write,Manually sync heat level if out of sync with stove
V14,Thermostat Zone,Integer,0,3,0,,Write,Select which zone controls the thermostat (0=Main 1=Fan1 2=Fan2 3=Fan3)
V15,Remote Zone Temperature,Double,0,120,70,°F,Read,Temperature from selected remote zone
V16,Fan 1 OFF,Integer,0,1,0,,Write,Turn Fan 1 OFF
V17,Fan 1 LOW,Integer,0,1,0,,Write,Set Fan 1 to LOW speed
V18,Fan 1 MEDIUM,Integer,0,1,0,,Write,Set Fan 1 to MEDIUM speed
V19,Fan 1 HIGH,Integer,0,1,0,,Write,Set Fan 1 to HIGH speed
V20,Fan 1 Light,Integer,0,1,0,,Write,Toggle Fan 1 light
V21,Fan 2 OFF,Integer,0,1,0,,Write,Turn Fan 2 OFF
V22,Fan 2 LOW,Integer,0,1,0,,Write,Set Fan 2 to LOW speed
V23,Fan 2 MEDIUM,Integer,0,1,0,,Write,Set Fan 2 to MEDIUM speed
V24,Fan 2 HIGH,Integer,0,1,0,,Write,Set Fan 2 to HIGH speed
V25,Fan 2 Light,Integer,0,1,0,,Write,Toggle Fan 2 light
V26,Fan 3 OFF,Integer,0,1,0,,Write,Turn Fan 3 OFF
V27,Fan 3 LOW,Integer,0,1,0,,Write,Set Fan 3 to LOW speed
V28,Fan 3 MEDIUM,Integer,0,1,0,,Write,Set Fan 3 to MEDIUM speed
V29,Fan 3 HIGH,Integer,0,1,0,,Write,Set Fan 3 to HIGH speed
V30,Fan 3 Light,Integer,0,1,0,,Write,Toggle Fan 3 light
V31,RF Learning Mode,Integer,0,1,0,,Write,Activate RF code learning mode for fan remotes
V32,Auto Equalization,Integer,0,1,0,,Read/Write,Enable temperature equalization learning mode
V33,Temp Diff Threshold,Double,1,10,3,°F,Write,Temperature difference threshold for equalization
V34,Learning Status,String,,,System ready,,Read,Display learning system status and sample count
V35,Reset Learning Data,Integer,0,1,0,,Write,Reset all learned temperature patterns
```

---

## Individual Datastream Definitions

### Temperature & Humidity Sensors

#### V0 - Local Temperature
```json
{
  "pin": "V0",
  "name": "Local Temperature",
  "dataType": "double",
  "min": 0,
  "max": 120,
  "default": 70,
  "unit": "°F",
  "direction": "read",
  "updateFrequency": "Every 5 minutes",
  "description": "Main DHT11 temperature sensor reading from Zone 0 (stove/main area)"
}
```

#### V2 - Local Humidity
```json
{
  "pin": "V2",
  "name": "Local Humidity",
  "dataType": "integer",
  "min": 0,
  "max": 100,
  "default": 50,
  "unit": "%",
  "direction": "read",
  "updateFrequency": "Every 5 minutes",
  "description": "Main DHT11 humidity sensor reading"
}
```

#### V14 - Thermostat Zone Selector
```json
{
  "pin": "V14",
  "name": "Thermostat Zone",
  "dataType": "integer",
  "min": 0,
  "max": 3,
  "default": 0,
  "unit": "",
  "direction": "write",
  "options": ["Zone 0 (Main)", "Zone 1 (Fan 1)", "Zone 2 (Fan 2)", "Zone 3 (Fan 3)"],
  "description": "Select which zone temperature controls the pellet stove thermostat"
}
```

#### V15 - Remote Zone Temperature
```json
{
  "pin": "V15",
  "name": "Remote Zone Temperature",
  "dataType": "double",
  "min": 0,
  "max": 120,
  "default": 70,
  "unit": "°F",
  "direction": "read",
  "updateFrequency": "Every 5 minutes (per zone)",
  "description": "Temperature reading from remote ESP32 sensor (Zones 1-3)"
}
```

---

### Pellet Stove Control

#### V3 - Stove Power ON
```json
{
  "pin": "V3",
  "name": "Stove Power ON",
  "dataType": "integer",
  "min": 0,
  "max": 1,
  "default": 0,
  "unit": "",
  "direction": "write",
  "widgetType": "button",
  "buttonMode": "push",
  "description": "Turn pellet stove ON via IR remote command"
}
```

#### V4 - Stove Power OFF
```json
{
  "pin": "V4",
  "name": "Stove Power OFF",
  "dataType": "integer",
  "min": 0,
  "max": 1,
  "default": 0,
  "unit": "",
  "direction": "write",
  "widgetType": "button",
  "buttonMode": "push",
  "description": "Turn pellet stove OFF via IR remote command"
}
```

#### V5 - Target Temperature
```json
{
  "pin": "V5",
  "name": "Target Temperature",
  "dataType": "double",
  "min": 60,
  "max": 80,
  "default": 70,
  "unit": "°F",
  "step": 1,
  "direction": "write",
  "widgetType": "slider",
  "description": "Desired temperature setpoint for automatic mode"
}
```

#### V6 - Auto Mode
```json
{
  "pin": "V6",
  "name": "Auto Mode",
  "dataType": "integer",
  "min": 0,
  "max": 1,
  "default": 0,
  "unit": "",
  "direction": "read/write",
  "widgetType": "switch",
  "description": "Enable automatic temperature control (PID-style heat adjustment)"
}
```

#### V7 - IR Learning Mode
```json
{
  "pin": "V7",
  "name": "IR Learning Mode",
  "dataType": "integer",
  "min": 0,
  "max": 1,
  "default": 0,
  "unit": "",
  "direction": "write",
  "widgetType": "button",
  "buttonMode": "push",
  "description": "Activate IR learning to capture stove remote codes (one-time setup)"
}
```

#### V8 - Heat Level UP
```json
{
  "pin": "V8",
  "name": "Heat Level UP",
  "dataType": "integer",
  "min": 0,
  "max": 1,
  "default": 0,
  "unit": "",
  "direction": "write",
  "widgetType": "button",
  "buttonMode": "push",
  "description": "Manually increase heat level by 1 (1→2, 2→3, etc.)"
}
```

#### V9 - Heat Level DOWN
```json
{
  "pin": "V9",
  "name": "Heat Level DOWN",
  "dataType": "integer",
  "min": 0,
  "max": 1,
  "default": 0,
  "unit": "",
  "direction": "write",
  "widgetType": "button",
  "buttonMode": "push",
  "description": "Manually decrease heat level by 1 (5→4, 4→3, etc.)"
}
```

#### V10 - Current Heat Level
```json
{
  "pin": "V10",
  "name": "Current Heat Level",
  "dataType": "integer",
  "min": 0,
  "max": 5,
  "default": 0,
  "unit": "/5",
  "direction": "read",
  "description": "Current heat setting (0=OFF, 1=Low, 2-4=Medium, 5=High)"
}
```

#### V11 - Stove Status
```json
{
  "pin": "V11",
  "name": "Stove Status",
  "dataType": "integer",
  "min": 0,
  "max": 1,
  "default": 0,
  "unit": "",
  "direction": "read",
  "widgetType": "led",
  "description": "Stove power status (0=OFF, 1=ON)"
}
```

#### V12 - Adjustment Cooldown
```json
{
  "pin": "V12",
  "name": "Adjustment Cooldown",
  "dataType": "integer",
  "min": 5,
  "max": 30,
  "default": 15,
  "unit": "min",
  "step": 1,
  "direction": "write",
  "widgetType": "slider",
  "description": "Minimum time between automatic heat adjustments (prevents rapid cycling)"
}
```

#### V13 - Manual Heat Sync
```json
{
  "pin": "V13",
  "name": "Manual Heat Sync",
  "dataType": "integer",
  "min": 0,
  "max": 5,
  "default": 3,
  "unit": "",
  "step": 1,
  "direction": "write",
  "widgetType": "slider",
  "description": "Sync ESP32 heat level with actual stove if they become out of sync"
}
```

---

### Ceiling Fan Controls (433MHz RF)

#### V16 - Fan 1 OFF
```json
{
  "pin": "V16",
  "name": "Fan 1 OFF",
  "dataType": "integer",
  "min": 0,
  "max": 1,
  "default": 0,
  "unit": "",
  "direction": "write",
  "widgetType": "button",
  "buttonMode": "push",
  "description": "Turn ceiling Fan 1 OFF via RF remote code"
}
```

#### V17 - Fan 1 LOW
```json
{
  "pin": "V17",
  "name": "Fan 1 LOW",
  "dataType": "integer",
  "min": 0,
  "max": 1,
  "default": 0,
  "unit": "",
  "direction": "write",
  "widgetType": "button",
  "buttonMode": "push",
  "description": "Set ceiling Fan 1 to LOW speed via RF remote code"
}
```

#### V18 - Fan 1 MEDIUM
```json
{
  "pin": "V18",
  "name": "Fan 1 MEDIUM",
  "dataType": "integer",
  "min": 0,
  "max": 1,
  "default": 0,
  "unit": "",
  "direction": "write",
  "widgetType": "button",
  "buttonMode": "push",
  "description": "Set ceiling Fan 1 to MEDIUM speed via RF remote code"
}
```

#### V19 - Fan 1 HIGH
```json
{
  "pin": "V19",
  "name": "Fan 1 HIGH",
  "dataType": "integer",
  "min": 0,
  "max": 1,
  "default": 0,
  "unit": "",
  "direction": "write",
  "widgetType": "button",
  "buttonMode": "push",
  "description": "Set ceiling Fan 1 to HIGH speed via RF remote code"
}
```

#### V20 - Fan 1 Light
```json
{
  "pin": "V20",
  "name": "Fan 1 Light",
  "dataType": "integer",
  "min": 0,
  "max": 1,
  "default": 0,
  "unit": "",
  "direction": "write",
  "widgetType": "button",
  "buttonMode": "push",
  "description": "Toggle ceiling Fan 1 light via RF remote code"
}
```

#### V21-V25 - Fan 2 Controls
*Same structure as Fan 1 (V16-V20), controlling Fan 2*

#### V26-V30 - Fan 3 Controls
*Same structure as Fan 1 (V16-V20), controlling Fan 3*

#### V31 - RF Learning Mode
```json
{
  "pin": "V31",
  "name": "RF Learning Mode",
  "dataType": "integer",
  "min": 0,
  "max": 1,
  "default": 0,
  "unit": "",
  "direction": "write",
  "widgetType": "button",
  "buttonMode": "push",
  "description": "Activate RF learning to capture all fan remote codes (15 codes total)"
}
```

---

### Temperature Equalization Learning

#### V32 - Auto Equalization Mode
```json
{
  "pin": "V32",
  "name": "Auto Equalization",
  "dataType": "integer",
  "min": 0,
  "max": 1,
  "default": 0,
  "unit": "",
  "direction": "read/write",
  "widgetType": "switch",
  "description": "Enable automatic temperature equalization using learned fan patterns"
}
```

#### V33 - Temperature Difference Threshold
```json
{
  "pin": "V33",
  "name": "Temp Diff Threshold",
  "dataType": "double",
  "min": 1,
  "max": 10,
  "default": 3,
  "unit": "°F",
  "step": 0.5,
  "direction": "write",
  "widgetType": "slider",
  "description": "Temperature difference between zones that triggers equalization"
}
```

#### V34 - Learning Status
```json
{
  "pin": "V34",
  "name": "Learning Status",
  "dataType": "string",
  "min": null,
  "max": null,
  "default": "System ready",
  "unit": "",
  "direction": "read",
  "widgetType": "labeled_value",
  "description": "Display current learning progress and sample count"
}
```

#### V35 - Reset Learning Data
```json
{
  "pin": "V35",
  "name": "Reset Learning Data",
  "dataType": "integer",
  "min": 0,
  "max": 1,
  "default": 0,
  "unit": "",
  "direction": "write",
  "widgetType": "button",
  "buttonMode": "push",
  "description": "Clear all learned temperature patterns and start fresh"
}
```

---

## Simplified Format for Blynk AI

### Copy-paste format for AI assistants:

```
TEMPERATURE SENSORS:
- V0: Local Temperature (double, 0-120°F, read-only, updates every 5 min)
- V2: Local Humidity (integer, 0-100%, read-only, updates every 5 min)
- V14: Thermostat Zone Selector (integer, 0-3, write, options: Zone 0/1/2/3)
- V15: Remote Zone Temperature (double, 0-120°F, read-only, updates every 5 min)

STOVE CONTROLS:
- V3: Stove ON Button (integer, 0-1, write, push button)
- V4: Stove OFF Button (integer, 0-1, write, push button)
- V5: Target Temperature (double, 60-80°F, write, slider with step=1)
- V6: Auto Mode Switch (integer, 0-1, read/write, toggle switch)
- V7: IR Learning Button (integer, 0-1, write, push button)
- V8: Heat UP Button (integer, 0-1, write, push button)
- V9: Heat DOWN Button (integer, 0-1, write, push button)
- V10: Current Heat Level (integer, 0-5, read-only, display)
- V11: Stove Status LED (integer, 0-1, read-only, LED indicator)
- V12: Adjustment Cooldown (integer, 5-30 min, write, slider with step=1)
- V13: Manual Heat Sync (integer, 0-5, write, slider with step=1)

CEILING FANS (RF 433MHz):
Fan 1:
- V16: OFF (integer, 0-1, write, push button)
- V17: LOW (integer, 0-1, write, push button)
- V18: MEDIUM (integer, 0-1, write, push button)
- V19: HIGH (integer, 0-1, write, push button)
- V20: Light (integer, 0-1, write, push button)

Fan 2:
- V21: OFF (integer, 0-1, write, push button)
- V22: LOW (integer, 0-1, write, push button)
- V23: MEDIUM (integer, 0-1, write, push button)
- V24: HIGH (integer, 0-1, write, push button)
- V25: Light (integer, 0-1, write, push button)

Fan 3:
- V26: OFF (integer, 0-1, write, push button)
- V27: LOW (integer, 0-1, write, push button)
- V28: MEDIUM (integer, 0-1, write, push button)
- V29: HIGH (integer, 0-1, write, push button)
- V30: Light (integer, 0-1, write, push button)

RF Learning:
- V31: RF Learning Button (integer, 0-1, write, push button)

TEMPERATURE LEARNING:
- V32: Auto Equalization Switch (integer, 0-1, read/write, toggle switch)
- V33: Temp Diff Threshold (double, 1-10°F, write, slider with step=0.5)
- V34: Learning Status (string, read-only, text display)
- V35: Reset Learning Button (integer, 0-1, write, push button)
```

---

## Update Frequencies (Message Optimization)

| Datastream Type | Frequency | Daily Messages |
|---|---|---|
| Temperature sensors (V0, V2, V15) | Every 5 minutes | 288 per zone |
| Stove status updates (V10, V11) | On change only | ~20-50 |
| User button presses (V3-V9, V16-V35) | Immediate | ~50-100 |
| Auto adjustments | Every 15+ min | ~20-50 |
| **TOTAL** | **—** | **~600-800/day** |

---

## Data Direction Summary

**Read-only (ESP32 → Blynk):**
- V0, V2, V10, V11, V15, V34

**Write-only (Blynk → ESP32):**
- V3, V4, V7, V8, V9, V12, V13, V14, V16-V31, V33, V35

**Read/Write (Bidirectional):**
- V5, V6, V32

---

## Notes for Blynk AI Configuration

1. **All buttons use PUSH mode**, not SWITCH mode
2. **Sliders should "send on release"** to reduce message usage
3. **Temperature displays** show 1 decimal place
4. **Humidity displays** show 0 decimal places
5. **Heat level** is displayed as "X/5" format
6. **LED widget** (V11) uses threshold=1, color=red for ON, gray for OFF
7. **Update interval** for all read pins: 1 second (app display refresh)
8. **Data is pushed from ESP32**, not polled by Blynk

---

**Last Updated**: November 2024
**Firmware Version**: Arduino_TCM v4.0
**Total Datastreams**: 36 (V0-V35)
**Estimated Message Usage**: 600-800/day

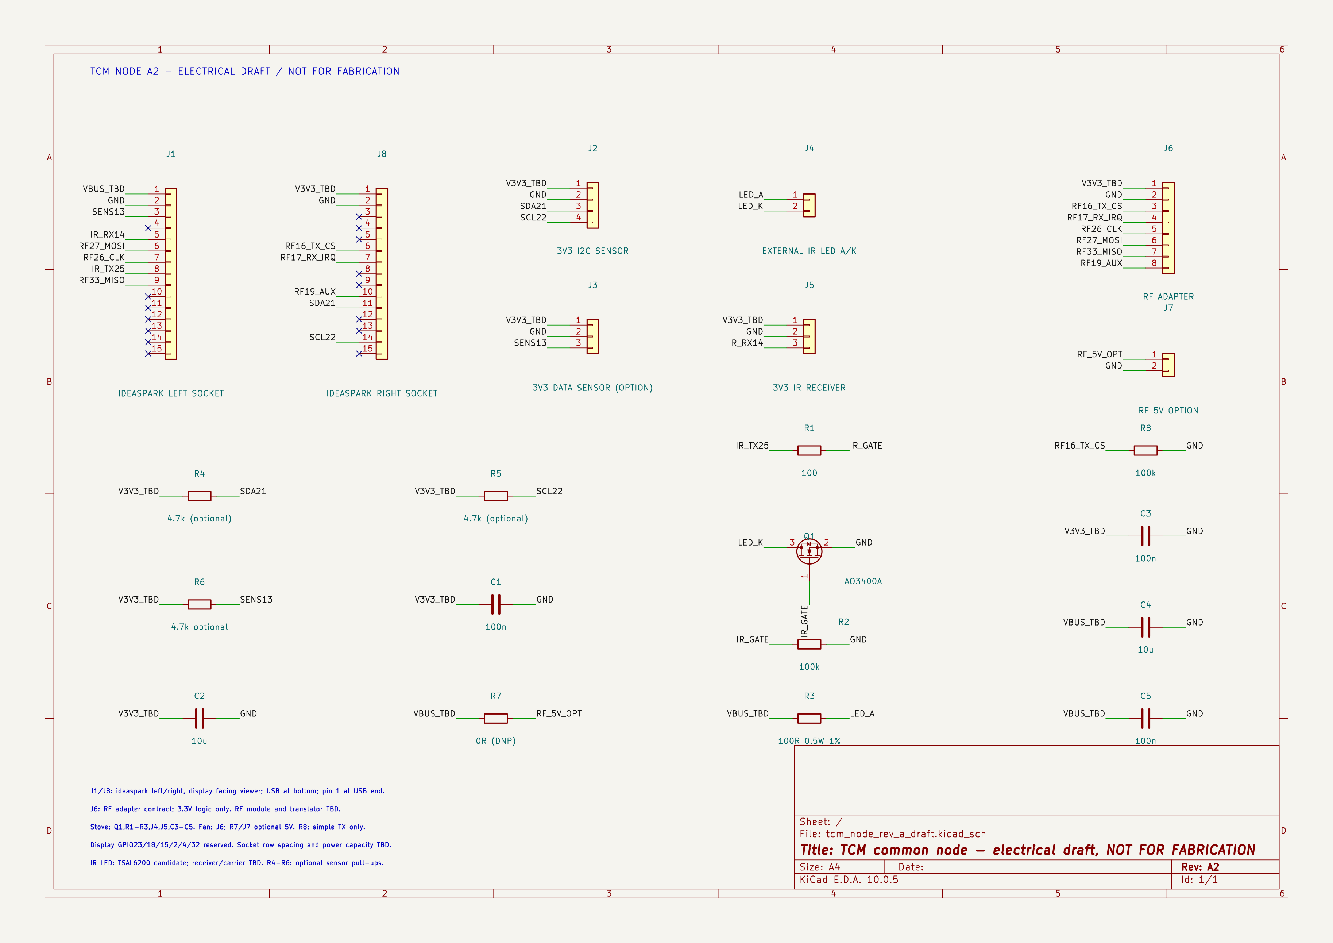
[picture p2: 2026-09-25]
hardware/preview/tcm_node_rev_a_draft.png

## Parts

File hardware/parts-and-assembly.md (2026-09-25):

# A2 component and assembly plan

Engineering selection draft, not an orderable production BOM. Package selections below are design choices; exact resistor/capacitor manufacturer part numbers remain to be qualified. All 14 discrete components have installed KiCad footprints. The eight connector footprints remain unassigned.

| References | Quantity per fully populated board | Electrical specification target | Package | Stove | Fan |
| --- | ---: | --- | --- | --- | --- |
| R1 | 1 | 100 ohm, 1%, at least 0.125 W | 0805 | Fit | Omit |
| R2 | 1 | 100 kohm, 1%, at least 0.125 W | 0805 | Fit | Omit |
| R3 | 1 | 100 ohm, 1%, at least 0.5 W after ambient derating | 2010 | Fit | Omit |
| R4, R5 | 2 | 4.7 kohm, 1%, at least 0.125 W | 0805 | Only if I2C sensor needs pull-ups | Same |
| R6 | 1 | 4.7 kohm, 1%, at least 0.125 W | 0805 | Only for compatible single-data-wire sensor | Same |
| R7 | 1 | Zero-ohm link, current rating matched to selected radio | 0805 | Omit | Normally omit; populate only for approved 5 V adapter power |
| R8 | 1 | 100 kohm, 1%, at least 0.125 W | 0805 | Omit | Only for simple active-high RF TX; omit for SPI |
| C1 | 1 | 100 nF, X7R, 16 V minimum, 10% | 0805 | Fit | Fit |
| C2 | 1 | 10 uF nominal, X7R, 16 V minimum, 20% | 1210 | Fit | Fit |
| C3, C5 | 2 | 100 nF, X7R, 16 V minimum, 10% | 0805 | Fit | Omit |
| C4 | 1 | 10 uF nominal, X7R, 16 V minimum, 20% | 1210 | Fit | Omit |
| Q1 | 1 | AO3400A; gate pad 1, source 2, drain 3 | SOT-23-3 | Fit | Omit |

Capacitor nominal value and package do not guarantee effective capacitance at DC bias. Qualify exact capacitor parts against their curves. A 2010 footprint does not itself guarantee 0.5 W: choose a resistor whose rated and derated power satisfies the IR calculation in node-circuit-draft.md. R7 must not be selected solely by package size.

## Connector and external-module requirements

| Reference | Positions | Purpose | Selection status |
| --- | ---: | --- | --- |
| J1, J8 | 15 each | Left/right ideaspark sockets | Pin order mapped from original product image; pitch, spacing, mating height and footprint not frozen |
| J2 | 4 | I2C sensor: 3.3 V, GND, SDA, SCL | Connector/cable and sensor part pending |
| J3 | 3 | Alternative sensor: 3.3 V, GND, DATA | Populate only if selected sensor uses this interface |
| J4 | 2 | IR LED anode / switched cathode | Polarized connector desired; cable and part pending |
| J5 | 3 | IR receiver: 3.3 V, GND, output | Receiver part, protocol carrier and cable pending |
| J6 | 8 | RF adapter power and logic | Radio module, voltage conversion and connector pending |
| J7 | 2 | Optional RF 5 V branch | Populate only with approved R7/radio configuration |

External parts are not included in the 22 schematic components: one ideaspark board per node, selected temperature sensor, USB wall adapter/cable, stove IR emitter (TSAL6200 candidate) and receiver, fan radio adapter/antenna, enclosure and mounting hardware. The CrowPanel is a separate purchased assembly.

## Assembly control

DNP means do not populate. Conditional populations are specified here; the generic connector generator does not encode independent KiCad stove/fan assembly variants. Do not send an unfiltered schematic BOM to an assembler. Produce separate released BOMs after RF and sensor selection.

Default assumptions for first bench work: no R7 or J7; no R8 until the radio's idle behavior is known; no optional sensor pull-ups until the selected module is checked. Use current-limited bench checks of the verified power path before fitting powered peripherals.

## Remaining release gates

1. Confirm socket geometry and carrier enclosure clearance.
2. Verify USB-to-VIN behavior and available 3.3 V peripheral current on the actual ideaspark board; do not equate the VIN label with a verified USB output.
3. Select sensor and IR receiver; confirm voltage limits and stove protocol.
4. Identify fan remotes and verify RF frequency, modulation, addressing and replay compatibility.
5. Complete connector selection, footprint assignment, PCB placement, routing and DRC.
6. Build separate stove/fan assembly BOMs and validate startup, reset, communication loss and command deduplication.

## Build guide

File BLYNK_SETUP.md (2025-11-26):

# Blynk Dashboard Setup Guide

Complete guide for setting up your Blynk dashboard to control the Arduino TCM Smart Home Climate Controller.

---

## Table of Contents
- [Blynk Account Setup](#blynk-account-setup)
- [Virtual Pin Reference](#virtual-pin-reference)
- [Dashboard Widgets](#dashboard-widgets)
- [Widget Configuration Details](#widget-configuration-details)
- [Message Usage Optimization](#message-usage-optimization)
- [Troubleshooting](#troubleshooting)

---

## Blynk Account Setup

### 1. Create Blynk Account
1. Download **Blynk Legacy** app (not Blynk IoT) from App Store or Google Play
2. Create a free account
3. Create a new project:
   - **Project Name**: "Pellet Stove Control" (or your choice)
   - **Device**: ESP32
   - **Connection Type**: WiFi
4. You'll receive an **Auth Token** via email - this is already in your code

### 2. Get Auth Token
Your current Auth Token is already configured in the code:
```
39B95_5S2gbtY8hGCdPOEz4XOiyVqlpz
```

### 3. Free Tier Limits
- **Energy**: 2000 points (each widget costs energy)
- **Messages**: Unlimited on Blynk Legacy (but optimized to ~600/day in this project)

---

## Virtual Pin Reference

### Temperature & Humidity Sensors
| Pin | Widget Type | Purpose | Update Frequency |
|-----|---|---|---|
| V0  | Value Display | Local temperature (°F) | Every 5 minutes |
| V2  | Value Display | Local humidity (%) | Every 5 minutes |
| V14 | Segmented Switch | Zone selector (0-3) | On change |
| V15 | Value Display | Remote zone temperature | Every 5 minutes |

### Pellet Stove Controls
| Pin | Widget Type | Purpose | Update Frequency |
|-----|---|---|---|
| V3  | Button | Turn stove ON | On press |
| V4  | Button | Turn stove OFF | On press |
| V5  | Slider | Target temperature (60-80°F) | On change |
| V6  | Switch | Auto mode ON/OFF | On change |
| V8  | Button | Manual heat UP | On press |
| V9  | Button | Manual heat DOWN | On press |
| V10 | Value Display | Current heat level (1-5) | On change |
| V11 | LED | Stove status (On/Off) | On change |
| V12 | Slider | Cooldown period (5-30 min) | On change |
| V13 | Slider | Manual heat sync (0-5) | On change |

### IR Learning
| Pin | Widget Type | Purpose | Update Frequency |
|-----|---|---|---|
| V7  | Button | IR learning mode | On press |

### Ceiling Fan Controls (433MHz RF)

#### Fan 1
| Pin | Widget Type | Purpose | Update Frequency |
|-----|---|---|---|
| V16 | Button | Fan 1 OFF | On press |
| V17 | Button | Fan 1 LOW speed | On press |
| V18 | Button | Fan 1 MEDIUM speed | On press |
| V19 | Button | Fan 1 HIGH speed | On press |
| V20 | Button | Fan 1 Light toggle | On press |

#### Fan 2
| Pin | Widget Type | Purpose | Update Frequency |
|-----|---|---|---|
| V21 | Button | Fan 2 OFF | On press |
| V22 | Button | Fan 2 LOW speed | On press |
| V23 | Button | Fan 2 MEDIUM speed | On press |
| V24 | Button | Fan 2 HIGH speed | On press |
| V25 | Button | Fan 2 Light toggle | On press |

#### Fan 3
| Pin | Widget Type | Purpose | Update Frequency |
|-----|---|---|---|
| V26 | Button | Fan 3 OFF | On press |
| V27 | Button | Fan 3 LOW speed | On press |
| V28 | Button | Fan 3 MEDIUM speed | On press |
| V29 | Button | Fan 3 HIGH speed | On press |
| V30 | Button | Fan 3 Light toggle | On press |

#### RF Learning
| Pin | Widget Type | Purpose | Update Frequency |
|-----|---|---|---|
| V31 | Button | RF learning mode | On press |

### Temperature Equalization Learning
| Pin | Widget Type | Purpose | Update Frequency |
|-----|---|---|---|
| V32 | Switch | Auto-Equalization mode | On change |
| V33 | Slider | Temp difference threshold (1-10°F) | On change |
| V34 | Labeled Value | Learning status display | On change |
| V35 | Button | Reset all learning data | On press |

---

## Dashboard Widgets

Here's the recommended dashboard layout organized by function:

### Tab 1: Main Control (Home Screen)

#### Temperature Display Section
1. **Value Display** → V0
   - **Title**: "Room Temp"
   - **Units**: °F
   - **Decimals**: 1
   - **Size**: 2x1
   - **Font Size**: Large

2. **Value Display** → V2
   - **Title**: "Humidity"
   - **Units**: %
   - **Decimals**: 0
   - **Size**: 2x1

3. **Value Display** → V15
   - **Title**: "Remote Zone"
   - **Units**: °F
   - **Decimals**: 1
   - **Size**: 2x1

#### Stove Control Section
4. **LED** → V11
   - **Title**: "Stove Status"
   - **Size**: 1x1
   - **Color**: Red when ON, Gray when OFF

5. **Value Display** → V10
   - **Title**: "Heat Level"
   - **Units**: /5
   - **Size**: 2x1
   - **Font Size**: Large

6. **Slider** → V5
   - **Title**: "Target Temp"
   - **Range**: 60-80
   - **Step**: 1
   - **Size**: 3x1
   - **Send on release**: ON

7. **Switch** → V6
   - **Title**: "Auto Mode"
   - **Size**: 2x1

#### Quick Controls
8. **Button** → V3
   - **Label**: "STOVE ON"
   - **Mode**: Push
   - **Size**: 2x1
   - **Color**: Green

9. **Button** → V4
   - **Label**: "STOVE OFF"
   - **Mode**: Push
   - **Size**: 2x1
   - **Color**: Red

10. **Button** → V8
    - **Label**: "Heat +"
    - **Mode**: Push
    - **Size**: 1x1

11. **Button** → V9
    - **Label**: "Heat -"
    - **Mode**: Push
    - **Size**: 1x1

### Tab 2: Ceiling Fans

#### Fan 1 Controls
1. **Button** → V16
   - **Label**: "Fan 1 OFF"
   - **Mode**: Push
   - **Size**: 2x1
   - **Color**: Gray

2. **Button** → V17
   - **Label**: "Fan 1 LOW"
   - **Mode**: Push
   - **Size**: 2x1
   - **Color**: Green

3. **Button** → V18
   - **Label**: "Fan 1 MED"
   - **Mode**: Push
   - **Size**: 2x1
   - **Color**: Yellow

4. **Button** → V19
   - **Label**: "Fan 1 HIGH"
   - **Mode**: Push
   - **Size**: 2x1
   - **Color**: Red

5. **Button** → V20
   - **Label**: "Fan 1 Light"
   - **Mode**: Push
   - **Size**: 2x1
   - **Color**: Orange

#### Fan 2 Controls
6-10. **Same as Fan 1** but using V21-V25

#### Fan 3 Controls
11-15. **Same as Fan 1** but using V26-V30

### Tab 3: Advanced Settings

#### Zone Selection
1. **Segmented Switch** → V14
   - **Title**: "Thermostat Zone"
   - **Options**:
     - "Zone 0 (Main)"
     - "Zone 1 (Fan 1)"
     - "Zone 2 (Fan 2)"
     - "Zone 3 (Fan 3)"
   - **Size**: 4x1

#### Learning System
2. **Switch** → V32
   - **Title**: "Auto-Equalization"
   - **Size**: 3x1

3. **Slider** → V33
   - **Title**: "Temp Diff Threshold"
   - **Range**: 1-10
   - **Units**: °F
   - **Step**: 0.5
   - **Size**: 4x1

4. **Labeled Value** → V34
   - **Title**: "Learning Status"
   - **Size**: 4x1

5. **Button** → V35
   - **Label**: "Reset Learning"
   - **Mode**: Push
   - **Size**: 2x1
   - **Color**: Orange

#### System Settings
6. **Slider** → V12
   - **Title**: "Adjustment Cooldown"
   - **Range**: 5-30
   - **Units**: min
   - **Step**: 1
   - **Size**: 4x1
   - **Send on release**: ON

7. **Slider** → V13
   - **Title**: "Manual Heat Sync"
   - **Range**: 0-5
   - **Step**: 1
   - **Size**: 4x1
   - **Info**: Use if ESP32 heat level gets out of sync with actual stove

### Tab 4: Learning Mode (Setup Only)

#### IR Learning (One-time setup)
1. **Button** → V7
   - **Label**: "Learn IR Codes"
   - **Mode**: Push
   - **Size**: 3x1
   - **Color**: Blue
   - **Info**: Press, then follow Serial Monitor instructions

#### RF Learning (One-time setup)
2. **Button** → V31
   - **Label**: "Learn RF Codes"
   - **Mode**: Push
   - **Size**: 3x1
   - **Color**: Purple
   - **Info**: Press, then follow Serial Monitor for all 15 codes

#### Instructions Display
3. **Terminal** or **Labeled Value**
   - **Size**: 4x3
   - **Text**:
   ```
   IR LEARNING:
   1. Press "Learn IR Codes" button
   2. Point stove remote at receiver
   3. Press: Power ON, Power OFF,
      Heat UP, Heat DOWN
   4. Codes saved automatically

   RF LEARNING:
   1. Press "Learn RF Codes" button
   2. Press all buttons on each fan remote:
      Fan 1: OFF, LOW, MED, HIGH, LIGHT
      Fan 2: OFF, LOW, MED, HIGH, LIGHT
      Fan 3: OFF, LOW, MED, HIGH, LIGHT
   3. Codes saved automatically
   ```

---

## Widget Configuration Details

### Important Widget Settings

#### Buttons (V3, V4, V8, V9, V16-V30, V35)
- **Output**: 1
- **Mode**: PUSH (not SWITCH)
- **Send on release**: OFF
- **Write interval**: 100ms (default)

#### Switches (V6, V32)
- **Output**: 1 (ON) / 0 (OFF)
- **Mode**: SWITCH
- **Write interval**: 100ms

#### Sliders (V5, V12, V13, V33)
- **Send on release**: ON (recommended to reduce messages)
- **Write interval**: 100ms

#### Value Displays (V0, V2, V10, V15)
- **Reading frequency**: 1 second (display update)
- **Data comes from ESP32** (not polled by app)
- **Decimals**: 1 for temperature, 0 for others

#### LED (V11)
- **Color**: Red for ON, Gray for OFF
- **Threshold**: 1 (ON when value ≥ 1)

---

## Message Usage Optimization

### Current Configuration (Optimized)

Your system is configured to minimize Blynk message usage:

#### Message Frequency
- **Zone 0 (Local sensor)**: Every 5 minutes = **288 messages/day**
- **Zone 1 (Remote sensor)**: Every 5 minutes = **288 messages/day**
- **Zone 2 (Remote sensor)**: Every 5 minutes = **288 messages/day**
- **Zone 3 (Remote sensor)**: Every 5 minutes = **288 messages/day**
- **User actions** (buttons, sliders): ~50-100/day
- **Auto adjustments** (heat level changes): ~20-50/day

**Total: ~600-800 messages/day** ✅

### Previous Configuration (Before Optimization)
- Zone 0: Every 2 minutes = 720/day
- Zones 1-3: Every 30 seconds = 8,640/day
- **Total: ~10,000 messages/day** ❌

### Rate Limiting Details

The code implements smart rate limiting:
```cpp
// Blynk updates limited to every 5 minutes (300,000 ms)
const unsigned long BLYNK_UPDATE_INTERVAL = 300000;
```

- **ESP-NOW data**: Received every 30 seconds, but only sent to Blynk every 5 minutes
- **Local sensor**: Read and sent to Blynk every 5 minutes
- **LCD display**: Updated every 4 seconds (local only, no Blynk messages)
- **User actions**: Immediate (necessary for control)

### Adjusting Update Frequency

If you want to change the update frequency, edit this line in the code:
```cpp
const unsigned long BLYNK_UPDATE_INTERVAL = 300000;  // 5 minutes
```

Options:
- **1 minute**: `60000` (1,440 messages/day)
- **2 minutes**: `120000` (720 messages/day)
- **5 minutes**: `300000` (288 messages/day) ← Current
- **10 minutes**: `600000` (144 messages/day)

**Recommendation**: Keep at 5 minutes for good responsiveness without excessive usage.

---

## Troubleshooting

### Dashboard Not Updating

**Problem**: Temperature or status not updating in Blynk

**Solutions**:
1. Check WiFi connection on ESP32 (Serial Monitor shows WiFi status)
2. Use `WIFI` serial command to check connection
3. Verify Auth Token matches in code and app
4. Check Serial Monitor for "→ Blynk updated for Zone X" messages
5. Blynk Legacy servers occasionally have issues - wait a few minutes

### Buttons Not Working

**Problem**: Pressing buttons doesn't control stove/fans

**Solutions**:
1. Verify button mode is **PUSH** not **SWITCH**
2. Check IR/RF codes are learned (use V7/V31 learning mode)
3. Verify codes saved (Serial Monitor shows "✓ IR/RF codes loaded")
4. Check hardware connections (IR LED, RF transmitter)
5. Use serial commands to test: `ON`, `OFF`, `FAN1 LOW`, etc.

### Learning Mode Not Working

**Problem**: Can't learn IR or RF codes

**Solutions**:
1. Open Serial Monitor (115200 baud) to see learning progress
2. For IR: Point remote directly at receiver (GPIO14), very close (<6 inches)
3. For RF: May need RF receiver module connected to GPIO17
4. Press remote buttons firmly and hold for 1 second
5. If code shows as `0xFFFFFFFFFFFFFFFF`, press button again (repeat code)

### Out of Sync Heat Level

**Problem**: Blynk shows wrong heat level compared to actual stove

**Solutions**:
1. Use **V13 slider** (Manual Heat Sync) to sync ESP32 with actual stove level
2. After syncing, auto mode will work correctly
3. Alternatively, use serial command: `HEAT 3` (sets to level 3)

### Zone Temperatures Not Showing

**Problem**: Remote zones show 0.0°F or "OFFLINE"

**Solutions**:
1. Check remote sensor ESP32 is powered on
2. Verify `ZONE_ID` is set correctly in remote sensor code (1, 2, or 3)
3. Check main controller MAC address matches in remote sensor code
4. Serial Monitor shows "ESP-NOW: Received from Zone X" when working
5. Use `ZONES` serial command to check all zone status
6. Zones timeout after 5 minutes - check remote sensor DHT11 connections

### Auto Mode Won't Enable

**Problem**: Auto mode switch turns off immediately

**Possible Causes**:
1. **IR codes not learned** - Use V7 to learn codes first
2. **Stove is OFF** - Turn stove ON (V3) before enabling auto mode
3. **Sensor failure** - Check DHT11 sensor (use `TEMP` serial command)

### High Blynk Message Usage

**Problem**: Running out of message quota

**Solutions**:
1. Verify code has rate limiting (check `BLYNK_UPDATE_INTERVAL = 300000`)
2. Increase update interval to 10 minutes (`600000`)
3. Check for excessive button presses (each press = 1 message)
4. Use Serial commands for testing instead of Blynk app

---

## Energy Budget (Widget Costs)

Blynk Legacy free tier: **2000 energy points**

### Estimated Widget Costs
- Value Display: 100 energy
- Button: 200 energy
- Switch: 200 energy
- Slider: 200 energy
- LED: 100 energy
- Segmented Switch: 300 energy
- Labeled Value: 100 energy

### Recommended Dashboard: ~1800 energy

**Tab 1 (Main Control)**: ~1100 energy
- 3× Value Display (V0, V2, V15): 300
- 1× LED (V11): 100
- 2× Button (V3, V4): 400
- 2× Small Button (V8, V9): 400
- 2× Slider (V5, V10): 400
- 1× Switch (V6): 200

**Tab 2 (Fans)**: ~600 energy
- 15× Button (all fan controls): 600

**Tab 3 (Advanced)**: ~900 energy
- 1× Segmented Switch (V14): 300
- 3× Slider (V12, V13, V33): 600
- 1× Switch (V32): 200
- 1× Labeled Value (V34): 100
- 1× Button (V35): 200

**Total**: ~2600 energy (exceeds free tier)

### Budget-Friendly Option (~1400 energy)
- Use only Tab 1 and Tab 2
- Skip advanced settings (adjust via serial commands)
- Remove some decorative displays

---

## Quick Start Checklist

- [ ] 1. Install Blynk Legacy app
- [ ] 2. Create project with ESP32 device
- [ ] 3. Note Auth Token (already in code)
- [ ] 4. Create Tab 1: Main Control
  - [ ] Add temperature displays (V0, V2, V15)
  - [ ] Add stove controls (V3, V4, V5, V6, V11)
  - [ ] Add heat adjustment (V8, V9, V10)
- [ ] 5. Create Tab 2: Ceiling Fans
  - [ ] Add Fan 1 controls (V16-V20)
  - [ ] Add Fan 2 controls (V21-V25)
  - [ ] Add Fan 3 controls (V26-V30)
- [ ] 6. Upload code to ESP32
- [ ] 7. Open Serial Monitor (115200 baud)
- [ ] 8. Learn IR codes (V7 button + Serial Monitor)
- [ ] 9. Learn RF codes (V31 button + Serial Monitor)
- [ ] 10. Test stove control with V3/V4 buttons
- [ ] 11. Test fan controls
- [ ] 12. Set target temperature (V5)
- [ ] 13. Enable auto mode (V6)

---

## Support & Serial Commands

If Blynk isn't working, you can control everything via Serial Monitor (115200 baud):

### Essential Commands
```
HELP          - Show all commands
TEMP          - Test temperature sensor
STATUS        - Show system status
ZONES         - Show all zone temperatures
ON            - Turn stove on
OFF           - Turn stove off
HEAT 3        - Set heat level to 3
AUTO          - Enable auto mode
MANUAL        - Disable auto mode
TARGET 72     - Set target to 72°F
FAN1 LOW      - Set Fan 1 to LOW
WIFI          - Check WiFi status
```

For complete command list, type `HELP` in Serial Monitor.

---

**Last Updated**: November 2024
**Firmware Version**: Arduino_TCM v4.0 (4-Zone with Rate Limiting)
**Compatible with**: Blynk Legacy (not Blynk IoT)

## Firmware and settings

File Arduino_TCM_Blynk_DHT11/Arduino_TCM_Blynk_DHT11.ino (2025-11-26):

#define BLYNK_TEMPLATE_ID "TMPL24OkwKw_5"
#define BLYNK_TEMPLATE_NAME "test"
#include <WiFi.h>
#include <BlynkSimpleEsp32.h>
#include <DHT.h>
#include <IRremoteESP8266.h>
#include <IRsend.h>
#include <IRrecv.h>
#include <IRutils.h>
#include <Preferences.h>
#include <esp_now.h>
#include <esp_wifi.h>
#include <RCSwitch.h>
#include <Adafruit_GFX.h>    // Core graphics library
#include <Adafruit_ST7789.h> // ST7789 LCD library
#include <SPI.h>

// ST7789 LCD Configuration (135x240 in landscape mode = 240x135)
#define LCD_MOSI  23  // SPI MOSI - ESP32 D23
#define LCD_SCLK  18  // SPI Clock - ESP32 D18
#define LCD_CS    15  // Chip select - ESP32 D15
#define LCD_DC    2   // Data/Command - ESP32 D2
#define LCD_RST   4   // Reset - ESP32 D4
#define LCD_BLK   32  // Backlight - ESP32 D32
#define TFT_WIDTH  240
#define TFT_HEIGHT 135

// Define DHT11 pin and type
#define DHTPIN 13       // GPIO13 (moved from GPIO4 due to LCD conflict)
#define DHTTYPE DHT11   // DHT11 sensor

// Define IR pins
#define IR_RECV_PIN 14  // GPIO14 for IR receiver (VS1838B)
#define IR_SEND_PIN 5   // GPIO5 for IR LED transmitter (moved from GPIO15 due to LCD conflict)

// Define RF pins
#define RF_TRANSMIT_PIN 16  // GPIO16 for 433MHz RF transmitter
#define RF_RECEIVE_PIN 17   // GPIO17 for 433MHz RF receiver (optional)

// Blynk Auth Token
char auth[] = "39B95_5S2gbtY8hGCdPOEz4XOiyVqlpz";

// WiFi credentials
char ssid[] = "Pahouse 2.4";
char pass[] = "jennyjenny92";

// Virtual pins for Blynk
#define TEMP_VPIN V0            // Temperature (°F)
#define HUM_VPIN V2             // Humidity (%)
#define STOVE_ON_VPIN V3        // Stove ON button
#define STOVE_OFF_VPIN V4       // Stove OFF button
#define TEMP_SETPOINT_VPIN V5   // Target temperature setpoint
#define AUTO_MODE_VPIN V6       // Auto mode switch (0=Manual, 1=Auto)
#define LEARN_MODE_VPIN V7      // IR Learning mode button
#define MANUAL_HEAT_UP_VPIN V8  // Manual heat up button
#define MANUAL_HEAT_DOWN_VPIN V9 // Manual heat down button
#define HEAT_LEVEL_VPIN V10     // Current heat level display (1-5)
#define STOVE_STATUS_VPIN V11   // Stove status (On/Off)
#define COOLDOWN_VPIN V12       // Adjustment cooldown period (minutes)
#define HEAT_SYNC_VPIN V13      // Manual heat level sync (1-5)
#define ZONE_SELECT_VPIN V14    // Zone selector (0=Zone1, 1=Zone2, 2=Average)
#define REMOTE_TEMP_VPIN V15    // Remote zone temperature display

// Ceiling Fan Virtual Pins (V16-V28)
// Fan 1 Controls
#define FAN1_OFF_VPIN V16       // Fan 1 OFF button
#define FAN1_LOW_VPIN V17       // Fan 1 LOW speed
#define FAN1_MED_VPIN V18       // Fan 1 MEDIUM speed
#define FAN1_HIGH_VPIN V19      // Fan 1 HIGH speed
#define FAN1_LIGHT_VPIN V20     // Fan 1 Light toggle

// Fan 2 Controls
#define FAN2_OFF_VPIN V21       // Fan 2 OFF button
#define FAN2_LOW_VPIN V22       // Fan 2 LOW speed
#define FAN2_MED_VPIN V23       // Fan 2 MEDIUM speed
#define FAN2_HIGH_VPIN V24      // Fan 2 HIGH speed
#define FAN2_LIGHT_VPIN V25     // Fan 2 Light toggle

// Fan 3 Controls
#define FAN3_OFF_VPIN V26       // Fan 3 OFF button
#define FAN3_LOW_VPIN V27       // Fan 3 LOW speed
#define FAN3_MED_VPIN V28       // Fan 3 MEDIUM speed
#define FAN3_HIGH_VPIN V29      // Fan 3 HIGH speed
#define FAN3_LIGHT_VPIN V30     // Fan 3 Light toggle

// RF Learning Mode
#define RF_LEARN_MODE_VPIN V31  // RF Learning mode button

// Temperature Equalization Learning Virtual Pins
#define AUTO_EQUALIZE_VPIN V32    // Auto-equalization mode switch
#define TEMP_DIFF_THRESHOLD_VPIN V33  // Temperature difference threshold slider
#define LEARNING_STATUS_VPIN V34  // Learning status display
#define RESET_LEARNING_VPIN V35   // Reset learned data button

// Initialize components
DHT dht(DHTPIN, DHTTYPE);
IRsend irsend(IR_SEND_PIN);
IRrecv irrecv(IR_RECV_PIN);
decode_results results;
RCSwitch rfSwitch = RCSwitch();
Adafruit_ST7789 lcd = Adafruit_ST7789(LCD_CS, LCD_DC, LCD_RST);  // 135x240 display
BlynkTimer timer;
Preferences preferences;

// Stove control variables
bool stoveIsOn = false;
bool autoMode = false;
int currentHeatLevel = 3;           // Current heat level (1-5), starts at medium
float tempSetpoint = 70.0;          // Default target temperature in °F
float currentTemp = 0.0;
float tempHysteresis = 2.0;         // Temperature buffer for adjustment trigger
unsigned long lastAdjustmentTime = 0;
unsigned long adjustmentCooldown = 900000; // 15 minutes between auto adjustments (900000 ms)
int sensorFailCount = 0;            // Track consecutive sensor failures
const int MAX_SENSOR_FAILS = 3;     // Disable auto mode after this many failures

// Multi-zone temperature control (4 zones total)
#define TOTAL_ZONES 4
float zoneTemp[TOTAL_ZONES] = {0.0, 0.0, 0.0, 0.0};  // Temps for all 4 zones
float zoneHumidity[TOTAL_ZONES] = {0.0, 0.0, 0.0, 0.0};  // Humidity for all 4 zones
unsigned long lastZoneTempTime[TOTAL_ZONES] = {0, 0, 0, 0};  // Last update time per zone
const unsigned long REMOTE_TIMEOUT = 300000; // 5 minutes - consider remote offline if no update
int thermostatZone = 0;  // Zone 0 controls the pellet stove (main thermostat)
int activeZone = 0;      // Active zone for Blynk display (0-3, for backward compatibility)

// Zone assignments:
// Zone 0: Main/Stove area (local DHT11 on main controller)
// Zone 1: Fan 1 area (remote sensor #1)
// Zone 2: Fan 2 area (remote sensor #2)
// Zone 3: Fan 3 area (remote sensor #3)

// ESP-NOW data structure for receiving temperature
typedef struct {
  float temperature;
  float humidity;
  uint8_t sensorID;  // Identifier for multiple remote sensors
} RemoteSensorData;

RemoteSensorData incomingData;

// IR code storage (you'll capture these from your stove remote)
uint64_t irCode_PowerOn = 0;        // Store your stove's power ON button code
uint64_t irCode_PowerOff = 0;       // Store your stove's power OFF button code
uint64_t irCode_HeatUp = 0;         // Store heat increase code
uint64_t irCode_HeatDown = 0;       // Store heat decrease code
decode_type_t irProtocol = UNKNOWN; // Will be detected when learning

// Learning mode
bool learningMode = false;
int learningStep = 0;  // 0=PowerOn, 1=PowerOff, 2=HeatUp, 3=HeatDown

// RF code storage for ceiling fans (433MHz)
// Fan 1 codes
unsigned long fan1_Off = 0;
unsigned long fan1_Low = 0;
unsigned long fan1_Med = 0;
unsigned long fan1_High = 0;
unsigned long fan1_Light = 0;

// Fan 2 codes
unsigned long fan2_Off = 0;
unsigned long fan2_Low = 0;
unsigned long fan2_Med = 0;
unsigned long fan2_High = 0;
unsigned long fan2_Light = 0;

// Fan 3 codes
unsigned long fan3_Off = 0;
unsigned long fan3_Low = 0;
unsigned long fan3_Med = 0;
unsigned long fan3_High = 0;
unsigned long fan3_Light = 0;

// RF Learning mode
bool rfLearningMode = false;
int rfLearningStep = 0;  // 0-4: Fan1 codes, 5-9: Fan2 codes, 10-14: Fan3 codes
int rfBitLength = 24;    // Default bit length (will be detected)

// Temperature Equalization Learning System
#define MAX_LEARNING_SAMPLES 50  // Store up to 50 learning samples per fan/speed combination

// Fan state tracking
struct FanState {
  uint8_t speed;  // 0=Off, 1=Low, 2=Med, 3=High
  unsigned long lastChangeTime;
};

FanState fan1State = {0, 0};
FanState fan2State = {0, 0};
FanState fan3State = {0, 0};

// Learning data structure
struct TempLearningData {
  float zone1TempChange;  // Temperature change in Zone 1 (°F per minute)
  float zone2TempChange;  // Temperature change in Zone 2 (°F per minute)
  uint8_t sampleCount;    // Number of samples collected
  unsigned long lastUpdateTime;
};

// Learning model: [fanIndex][speedIndex] → temperature impact
// fanIndex: 0=Fan1, 1=Fan2, 2=Fan3
// speedIndex: 0=Off, 1=Low, 2=Med, 3=High
TempLearningData learningModel[3][4];

// Auto-equalization settings
bool autoEqualizationMode = false;
float tempDifferenceThreshold = 3.0;  // Start equalizing when zones differ by 3°F
unsigned long lastEqualizationAction = 0;
const unsigned long EQUALIZATION_COOLDOWN = 300000; // 5 minutes between actions

// Temperature tracking for learning
float lastZone1Temp = 0.0;
float lastZone2Temp = 0.0;
unsigned long lastTempSampleTime = 0;
const unsigned long TEMP_SAMPLE_INTERVAL = 60000; // Sample every 1 minute for learning

// LCD Display variables
unsigned long lastDisplayUpdate = 0;
const unsigned long DISPLAY_UPDATE_INTERVAL = 4000; // Update display every 4 seconds (page rotation)
bool displayInitialized = false;
int currentDisplayPage = 0;  // 0-4 for 5 different pages
const int TOTAL_DISPLAY_PAGES = 5;

// Blynk rate limiting - reduce message usage
unsigned long lastBlynkUpdate[TOTAL_ZONES] = {0, 0, 0, 0};  // Last Blynk update time per zone
const unsigned long BLYNK_UPDATE_INTERVAL = 300000;  // Update Blynk every 5 minutes (300,000 ms)
// This reduces Blynk messages from ~10,000/day to ~600/day

// Function to send IR command
void sendIRCommand(uint64_t code) {
  if (code == 0) {
    Serial.println("Error: IR code not set. Please learn codes first!");
    return;
  }

  Serial.print("Sending IR code: 0x");
  Serial.println(uint64ToString(code, HEX));

  // Send the code (adjust protocol if needed - NEC is common)
  irsend.sendNEC(code, 32);
  delay(100); // Small delay after sending
}

// Save IR codes to EEPROM/Flash
void saveIRCodes() {
  preferences.begin("stove", false);  // false = read/write mode
  preferences.putULong64("powerOn", irCode_PowerOn);
  preferences.putULong64("powerOff", irCode_PowerOff);
  preferences.putULong64("heatUp", irCode_HeatUp);
  preferences.putULong64("heatDown", irCode_HeatDown);
  preferences.end();
  Serial.println("IR codes saved to flash memory");
}

// Load IR codes from EEPROM/Flash
void loadIRCodes() {
  preferences.begin("stove", true);  // true = read-only mode
  irCode_PowerOn = preferences.getULong64("powerOn", 0);
  irCode_PowerOff = preferences.getULong64("powerOff", 0);
  irCode_HeatUp = preferences.getULong64("heatUp", 0);
  irCode_HeatDown = preferences.getULong64("heatDown", 0);
  preferences.end();

  if (irCode_PowerOn != 0 && irCode_PowerOff != 0) {
    Serial.println("✓ IR codes loaded from flash memory");
    Serial.print("  Power ON: 0x");
    Serial.println(uint64ToString(irCode_PowerOn, HEX));
    Serial.print("  Power OFF: 0x");
    Serial.println(uint64ToString(irCode_PowerOff, HEX));
    Serial.print("  Heat UP: 0x");
    Serial.println(uint64ToString(irCode_HeatUp, HEX));
    Serial.print("  Heat DOWN: 0x");
    Serial.println(uint64ToString(irCode_HeatDown, HEX));
  } else {
    Serial.println("No saved IR codes found - please use learning mode");
  }
}

// Function to send RF command
void sendRFCommand(unsigned long code, int bitLength) {
  if (code == 0) {
    Serial.println("Error: RF code not set. Please learn codes first!");
    return;
  }

  Serial.print("Sending RF code: ");
  Serial.print(code);
  Serial.print(" (");
  Serial.print(bitLength);
  Serial.println(" bits)");

  rfSwitch.send(code, bitLength);
  delay(100); // Small delay after sending
}

// Save RF codes to EEPROM/Flash
void saveRFCodes() {
  preferences.begin("fans", false);  // false = read/write mode

  // Fan 1 codes
  preferences.putULong("fan1_off", fan1_Off);
  preferences.putULong("fan1_low", fan1_Low);
  preferences.putULong("fan1_med", fan1_Med);
  preferences.putULong("fan1_high", fan1_High);
  preferences.putULong("fan1_light", fan1_Light);

  // Fan 2 codes
  preferences.putULong("fan2_off", fan2_Off);
  preferences.putULong("fan2_low", fan2_Low);
  preferences.putULong("fan2_med", fan2_Med);
  preferences.putULong("fan2_high", fan2_High);
  preferences.putULong("fan2_light", fan2_Light);

  // Fan 3 codes
  preferences.putULong("fan3_off", fan3_Off);
  preferences.putULong("fan3_low", fan3_Low);
  preferences.putULong("fan3_med", fan3_Med);
  preferences.putULong("fan3_high", fan3_High);
  preferences.putULong("fan3_light", fan3_Light);

  // Save bit length
  preferences.putInt("rfBitLen", rfBitLength);

  preferences.end();
  Serial.println("RF codes saved to flash memory");
}

// Load RF codes from EEPROM/Flash
void loadRFCodes() {
  preferences.begin("fans", true);  // true = read-only mode

  // Fan 1 codes
  fan1_Off = preferences.getULong("fan1_off", 0);
  fan1_Low = preferences.getULong("fan1_low", 0);
  fan1_Med = preferences.getULong("fan1_med", 0);
  fan1_High = preferences.getULong("fan1_high", 0);
  fan1_Light = preferences.getULong("fan1_light", 0);

  // Fan 2 codes
  fan2_Off = preferences.getULong("fan2_off", 0);
  fan2_Low = preferences.getULong("fan2_low", 0);
  fan2_Med = preferences.getULong("fan2_med", 0);
  fan2_High = preferences.getULong("fan2_high", 0);
  fan2_Light = preferences.getULong("fan2_light", 0);

  // Fan 3 codes
  fan3_Off = preferences.getULong("fan3_off", 0);
  fan3_Low = preferences.getULong("fan3_low", 0);
  fan3_Med = preferences.getULong("fan3_med", 0);
  fan3_High = preferences.getULong("fan3_high", 0);
  fan3_Light = preferences.getULong("fan3_light", 0);

  // Load bit length
  rfBitLength = preferences.getInt("rfBitLen", 24);

  preferences.end();

  if (fan1_Off != 0) {
    Serial.println("✓ RF codes loaded from flash memory");
    Serial.print("  Bit length: ");
    Serial.println(rfBitLength);
    Serial.println("  Fan codes loaded for 3 fans");
  } else {
    Serial.println("No saved RF codes found - please use RF learning mode");
  }
}

// ===== TEMPERATURE EQUALIZATION LEARNING SYSTEM =====

// Initialize learning model
void initLearningModel() {
  for (int fan = 0; fan < 3; fan++) {
    for (int speed = 0; speed < 4; speed++) {
      learningModel[fan][speed].zone1TempChange = 0.0;
      learningModel[fan][speed].zone2TempChange = 0.0;
      learningModel[fan][speed].sampleCount = 0;
      learningModel[fan][speed].lastUpdateTime = 0;
    }
  }
}

// Update fan state when fan command is sent
void updateFanState(uint8_t fanIndex, uint8_t newSpeed) {
  FanState* fan;

  switch(fanIndex) {
    case 0: fan = &fan1State; break;
    case 1: fan = &fan2State; break;
    case 2: fan = &fan3State; break;
    default: return;
  }

  fan->speed = newSpeed;
  fan->lastChangeTime = millis();

  Serial.print("Fan ");
  Serial.print(fanIndex + 1);
  Serial.print(" state updated: Speed ");
  Serial.println(newSpeed);
}

// Collect temperature samples and learn correlations
void collectTemperatureSample() {
  unsigned long currentTime = millis();

  // Only sample every minute
  if (currentTime - lastTempSampleTime < TEMP_SAMPLE_INTERVAL) {
    return;
  }

  // Need zone 1 active for learning (check if remote sensor is online)
  if (currentTime - lastZoneTempTime[1] > REMOTE_TIMEOUT) {
    return; // Zone 1 sensor offline
  }

  // Calculate temperature changes since last sample
  float zone1Change = zoneTemp[0] - lastZone1Temp;  // Zone 0 (main)
  float zone2Change = zoneTemp[1] - lastZone2Temp;  // Zone 1 (fan 1 area)

  // Calculate time elapsed in minutes
  float minutesElapsed = (currentTime - lastTempSampleTime) / 60000.0;

  if (minutesElapsed > 0 && lastTempSampleTime > 0) {
    // Temperature change rate (°F per minute)
    float zone1Rate = zone1Change / minutesElapsed;
    float zone2Rate = zone2Change / minutesElapsed;

    // Update learning model for each active fan
    for (int fan = 0; fan < 3; fan++) {
      FanState* fanState;
      switch(fan) {
        case 0: fanState = &fan1State; break;
        case 1: fanState = &fan2State; break;
        case 2: fanState = &fan3State; break;
      }

      // Only learn if fan has been in this state for at least 2 minutes
      if (currentTime - fanState->lastChangeTime >= 120000) {
        uint8_t speed = fanState->speed;
        TempLearningData* data = &learningModel[fan][speed];

        // Running average of temperature change rates
        if (data->sampleCount < MAX_LEARNING_SAMPLES) {
          // Add new sample
          data->zone1TempChange = ((data->zone1TempChange * data->sampleCount) + zone1Rate) / (data->sampleCount + 1);
          data->zone2TempChange = ((data->zone2TempChange * data->sampleCount) + zone2Rate) / (data->sampleCount + 1);
          data->sampleCount++;
          data->lastUpdateTime = currentTime;

          // Log learning progress
          if (data->sampleCount % 5 == 0) {
            Serial.print("Learning: Fan");
            Serial.print(fan + 1);
            Serial.print(" Speed");
            Serial.print(speed);
            Serial.print(" - Samples: ");
            Serial.print(data->sampleCount);
            Serial.print(" Z0: ");
            Serial.print(data->zone1TempChange, 3);
            Serial.print("°F/min Z1: ");
            Serial.print(data->zone2TempChange, 3);
            Serial.println("°F/min");
          }
        }
      }
    }
  }

  // Update last temperatures and time
  lastZone1Temp = zoneTemp[0];
  lastZone2Temp = zoneTemp[1];
  lastTempSampleTime = currentTime;
}

// Save learning data to EEPROM
void saveLearningData() {
  preferences.begin("templearn", false);

  for (int fan = 0; fan < 3; fan++) {
    for (int speed = 0; speed < 4; speed++) {
      String key = String(fan) + "_" + String(speed);
      preferences.putFloat((key + "_z1").c_str(), learningModel[fan][speed].zone1TempChange);
      preferences.putFloat((key + "_z2").c_str(), learningModel[fan][speed].zone2TempChange);
      preferences.putUChar((key + "_cnt").c_str(), learningModel[fan][speed].sampleCount);
    }
  }

  preferences.end();
  Serial.println("Learning data saved to flash memory");
}

// Load learning data from EEPROM
void loadLearningData() {
  preferences.begin("templearn", true);

  int totalSamples = 0;
  for (int fan = 0; fan < 3; fan++) {
    for (int speed = 0; speed < 4; speed++) {
      String key = String(fan) + "_" + String(speed);
      learningModel[fan][speed].zone1TempChange = preferences.getFloat((key + "_z1").c_str(), 0.0);
      learningModel[fan][speed].zone2TempChange = preferences.getFloat((key + "_z2").c_str(), 0.0);
      learningModel[fan][speed].sampleCount = preferences.getUChar((key + "_cnt").c_str(), 0);
      totalSamples += learningModel[fan][speed].sampleCount;
    }
  }

  preferences.end();

  if (totalSamples > 0) {
    Serial.println("✓ Temperature learning data loaded");
    Serial.print("  Total samples: ");
    Serial.println(totalSamples);
  } else {
    Serial.println("No learning data found - system will learn over time");
  }
}

// Auto-equalization: Use learned data to balance temperatures
void autoEqualizeTemperatures() {
  if (!autoEqualizationMode) return;

  unsigned long currentTime = millis();

  // Cooldown between actions
  if (currentTime - lastEqualizationAction < EQUALIZATION_COOLDOWN) {
    return;
  }

  // Need zone 1 active (check if remote sensor is online)
  if (currentTime - lastZoneTempTime[1] > REMOTE_TIMEOUT) {
    return;
  }

  // Calculate temperature difference between zones 0 and 1
  float tempDiff = zoneTemp[0] - zoneTemp[1];

  // Only act if difference exceeds threshold
  if (abs(tempDiff) < tempDifferenceThreshold) {
    return;
  }

  Serial.print("Temperature difference detected: ");
  Serial.print(tempDiff);
  Serial.println("°F");

  // Determine which zone needs cooling/warming
  bool zone1NeedsCooling = (tempDiff > 0);  // Zone 1 is warmer
  bool zone2NeedsCooling = (tempDiff < 0);  // Zone 2 is warmer

  // Find best fan/speed combination using learned data
  int bestFan = -1;
  int bestSpeed = -1;
  float bestEffect = 0.0;

  for (int fan = 0; fan < 3; fan++) {
    for (int speed = 1; speed < 4; speed++) {  // Skip speed 0 (OFF)
      TempLearningData* data = &learningModel[fan][speed];

      // Need at least 5 samples to trust the data
      if (data->sampleCount < 5) continue;

      // Calculate expected effect on temperature difference
      // Positive effect = reduces temperature difference
      float effect = 0.0;

      if (zone1NeedsCooling) {
        // Want to cool Zone 1 or warm Zone 2
        effect = -data->zone1TempChange + data->zone2TempChange;
      } else {
        // Want to warm Zone 1 or cool Zone 2
        effect = data->zone1TempChange - data->zone2TempChange;
      }

      // Find fan with best (most positive) effect
      if (effect > bestEffect) {
        bestEffect = effect;
        bestFan = fan;
        bestSpeed = speed;
      }
    }
  }

  // Execute best fan action
  if (bestFan >= 0 && bestSpeed >= 0) {
    Serial.print("Auto-Equalization: Running Fan ");
    Serial.print(bestFan + 1);
    Serial.print(" at speed ");
    Serial.print(bestSpeed);
    Serial.print(" (expected effect: ");
    Serial.print(bestEffect, 3);
    Serial.println("°F/min)");

    // Send fan command
    unsigned long code = 0;
    switch(bestFan) {
      case 0:
        code = (bestSpeed == 1) ? fan1_Low : (bestSpeed == 2) ? fan1_Med : fan1_High;
        break;
      case 1:
        code = (bestSpeed == 1) ? fan2_Low : (bestSpeed == 2) ? fan2_Med : fan2_High;
        break;
      case 2:
        code = (bestSpeed == 1) ? fan3_Low : (bestSpeed == 2) ? fan3_Med : fan3_High;
        break;
    }

    if (code != 0) {
      sendRFCommand(code, rfBitLength);
      updateFanState(bestFan, bestSpeed);
      lastEqualizationAction = currentTime;
    }
  } else {
    Serial.println("Auto-Equalization: Not enough learned data yet");
  }
}

// ===== END TEMPERATURE EQUALIZATION LEARNING SYSTEM =====
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
void loop() {
  Blynk.run();
  timer.run();
  processSerialCommand();  // Check for serial commands
}

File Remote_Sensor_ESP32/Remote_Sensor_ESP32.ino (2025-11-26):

// Remote Temperature Sensor for Multi-Zone Pellet Stove Control
// This ESP32 sends temperature data to the main controller via ESP-NOW

#include <WiFi.h>
#include <esp_now.h>
#include <esp_wifi.h>
#include <DHT.h>

// ZONE CONFIGURATION - Set this based on which zone this sensor is in
// Zone 1 = Fan 1 area
// Zone 2 = Fan 2 area
// Zone 3 = Fan 3 area
#define ZONE_ID 1       // CHANGE THIS: 1, 2, or 3

// DHT11 Configuration
#define DHTPIN 13       // GPIO13 (matching main controller)
#define DHTTYPE DHT11   // DHT11 sensor

// IMPORTANT: Replace with YOUR main controller's MAC address
// To find MAC address, upload this code to main ESP32 and check Serial Monitor
uint8_t mainControllerMAC[] = {0xFF, 0xFF, 0xFF, 0xFF, 0xFF, 0xFF};  // REPLACE THIS!

// WiFi credentials (needed for ESP-NOW to work properly)
const char* ssid = "Pahouse 2.4";       // Same as main controller
const char* password = "jennyjenny92";  // Same as main controller

// Initialize DHT sensor
DHT dht(DHTPIN, DHTTYPE);

// Data structure (must match main controller)
typedef struct {
  float temperature;
  float humidity;
  uint8_t sensorID;
} RemoteSensorData;

RemoteSensorData sensorData;

// Peer info for ESP-NOW
esp_now_peer_info_t peerInfo;

// Send interval (every 30 seconds)
unsigned long lastSendTime = 0;
const unsigned long sendInterval = 30000;

// Callback when data is sent
void onDataSent(const uint8_t *mac_addr, esp_now_send_status_t status) {
  Serial.print("Send Status: ");
  Serial.println(status == ESP_NOW_SEND_SUCCESS ? "Success" : "Fail");
}

void setup() {
  Serial.begin(115200);
  delay(1000);

  Serial.println("\n=== Remote Temperature Sensor ===");
  Serial.println("Zone 2 - ESP-NOW Transmitter");

  // Check if MAC address has been configured
  if (mainControllerMAC[0] == 0xFF && mainControllerMAC[1] == 0xFF &&
      mainControllerMAC[2] == 0xFF && mainControllerMAC[3] == 0xFF &&
      mainControllerMAC[4] == 0xFF && mainControllerMAC[5] == 0xFF) {
    Serial.println("\n*** ERROR: DEFAULT MAC ADDRESS DETECTED! ***");
    Serial.println("You MUST update 'mainControllerMAC' with your main controller's MAC address!");
    Serial.println("The system will continue but ESP-NOW will not work.");
    Serial.println("***********************************************\n");
  }

  // Initialize DHT sensor
  dht.begin();
  Serial.println("✓ DHT11 sensor initialized");

  // Connect to WiFi (required for ESP-NOW)
  WiFi.mode(WIFI_STA);
  WiFi.begin(ssid, password);
  Serial.print("Connecting to WiFi");

  // Add timeout for WiFi connection (30 seconds)
  int wifiTimeout = 0;
  while (WiFi.status() != WL_CONNECTED && wifiTimeout < 60) {
    delay(500);
    Serial.print(".");
    wifiTimeout++;
  }

  if (WiFi.status() == WL_CONNECTED) {
    Serial.println("\n✓ WiFi connected");
  } else {
    Serial.println("\n⚠ WiFi connection timeout!");
    Serial.println("ESP-NOW will still work on same WiFi channel");
  }

  // Print MAC address (needed for main controller setup)
  Serial.print("This device's MAC Address: ");
  Serial.println(WiFi.macAddress());
  Serial.println("Copy this MAC to the main controller if needed!");

  // Initialize ESP-NOW
  if (esp_now_init() != ESP_OK) {
    Serial.println("ERROR: ESP-NOW initialization failed!");
    Serial.println("System cannot function without ESP-NOW. Restarting in 10 seconds...");
    delay(10000);
    ESP.restart();
  }
  Serial.println("✓ ESP-NOW initialized");

  // Register send callback
  esp_now_register_send_cb(onDataSent);

  // Add main controller as peer
  memcpy(peerInfo.peer_addr, mainControllerMAC, 6);
  peerInfo.channel = 0;
  peerInfo.encrypt = false;

  if (esp_now_add_peer(&peerInfo) != ESP_OK) {
    Serial.println("ERROR: Failed to add peer!");
    Serial.println("Please verify the main controller MAC address is correct.");
    Serial.println("System will retry, but data may not be received...");
  } else {
    Serial.println("✓ Main controller added as peer");
  }

  // Set Zone ID from configuration
  sensorData.sensorID = ZONE_ID;
  Serial.print("This sensor is configured for Zone ");
  Serial.println(ZONE_ID);

  Serial.println("\n=== System Ready ===");
  Serial.println("Sending temperature data every 30 seconds...");
  Serial.println();
}

void loop() {
  unsigned long currentTime = millis();

  // Send data every 30 seconds
  if (currentTime - lastSendTime >= sendInterval) {
    lastSendTime = currentTime;

    // Read temperature and humidity
    float h = dht.readHumidity();
    float t = dht.readTemperature();
    float f = (t * 9.0 / 5.0) + 32.0;  // Convert to Fahrenheit

    // Check if readings are valid
    if (isnan(h) || isnan(t)) {
      Serial.println("Failed to read from DHT sensor!");
      return;
    }

    // Prepare data packet
    sensorData.temperature = f;
    sensorData.humidity = h;

    // Send data via ESP-NOW
    esp_err_t result = esp_now_send(mainControllerMAC, (uint8_t *) &sensorData, sizeof(sensorData));

    // Print to serial
    Serial.print("Sending - Temp: ");
    Serial.print(f);
    Serial.print("°F (");
    Serial.print(t);
    Serial.print("°C), Humidity: ");
    Serial.print(h);
    Serial.print("% - ");

    if (result == ESP_OK) {
      Serial.println("Sent successfully");
    } else {
      Serial.println("Error sending data");
    }
  }

  delay(100);  // Small delay
}

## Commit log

2025-11-22 Add Blynk DHT11 temperature and humidity monitoring system
    - Created Arduino sketch for ESP32 with DHT11 sensor integration
    - Implemented Blynk IoT connectivity for remote monitoring
    - Temperature sent to virtual pin V0 (in Fahrenheit)
    - Humidity sent to virtual pin V2
    - Data transmission every 5 minutes
    - Added comprehensive README with setup instructions and troubleshooting
2025-11-22 Add IR control and automated pellet stove functionality
    Major Features:
    - IR learning mode to capture pellet stove remote commands (Power, Heat Up, Heat Down)
    - VS1838B IR receiver integration on GPIO14
    - IR LED transmitter on GPIO15 with transistor circuit
    - Temperature-based automation with hysteresis (±2°F buffer)
    - Manual stove control via Blynk app
    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
2025-11-22 Redesign to PID-style heat level control instead of on/off automation
    Major Changes:
    - Replaced automatic on/off with heat level adjustment (1-5)
    - Manual on/off control via separate buttons (V3=ON, V4=OFF)
    - Auto mode now adjusts heat levels, not power state
    - 5-minute cooldown between automatic adjustments
    - Stove starts at heat level 3 when turned on
    Control Logic:
    - Temperature < setpoint-2°F → Increase heat level
    - Temperature > setpoint+2°F → Decrease heat level
    - Within ±2°F range → Maintain current level
    - Heat levels limited to 1 (min) through 5 (max)
    - Prevents command spam with cooldown timer
    New Blynk Virtual Pins:
    - V3: Stove ON button (manual)
    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
    [Arduino_TCM_Blynk_DHT11.ino]
2025-11-22 Add separate Power OFF IR code support
    Changes:
    - Added irCode_PowerOff variable for dedicated OFF button
    - Renamed irCode_Power to irCode_PowerOn for clarity
    - Updated learning mode to capture 4 IR codes instead of 3
    - Learning sequence: Power ON → Power OFF → Heat UP → Heat DOWN
    - turnStoveOn() now uses irCode_PowerOn
    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
2025-11-22 Add user-adjustable cooldown period and increase default to 15 minutes
    Changes to Arduino Sketch:
    - Changed default cooldown from 5 min to 15 min (900000 ms)
    - Added V12 virtual pin for cooldown period slider
    - Added BLYNK_WRITE(COOLDOWN_VPIN) handler
    - Cooldown adjustable in real-time (5-30 minutes)
    - Converts slider value (minutes) to milliseconds automatically
    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
2025-11-22 Add critical improvements: EEPROM storage, sensor protection, and heat sync
    Feature 1: EEPROM IR Code Storage
    - Added Preferences library for flash memory storage
    - IR codes automatically saved after learning
    - Codes loaded on startup - survive reboots/power cycles
    - No more re-learning codes after every restart
    - Saves 4 codes: PowerOn, PowerOff, HeatUp, HeatDown
    Feature 2: Sensor Failure Protection
    - Track consecutive DHT11 sensor failures
    - Auto-disable auto mode after 3 consecutive failures
    - Prevents automation from using stale temperature data
    - Reset counter on successful read
    - Serial output shows fail count and warnings
    Feature 3: Heat Level Sync (V13)
    - New virtual pin V13 for ma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
    [Arduino_TCM_Blynk_DHT11.ino]
2025-11-22 Add multi-zone temperature control with ESP-NOW
    Feature: Multi-Zone Temperature Control
    - Control stove based on temperature from different rooms
    - Uses ESP-NOW for fast, reliable wireless communication
    - No API limits or internet dependency
    - Automatic fallback to local sensor if remote fails
    Main Controller Changes:
    - Added ESP-NOW library support
    - New virtual pins: V14 (zone selector), V15 (remote temp)
    - Zone selection: Zone 1 (local), Zone 2 (remote), Average
    - Separate tracking for local vs remote temperatures
    - Smart temperature selection based on active zone
    - Remote sensor timeout detection (5 min)
    - Automatic fallback to Zone 1 if remote offline
    Zone Selection Logic:
    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
    [Arduino_TCM_Blynk_DHT11.ino, Remote_Sensor_ESP32.ino]
2025-11-22 Fix critical bugs and add input validation
    Main Controller Fixes:
    - Fix WiFi mode conflict: Set WIFI_AP_STA before Blynk.begin() for ESP-NOW compatibility
    - Add zone selector validation (must be 0-2) to prevent array out of bounds
    - Add cooldown slider bounds checking (5-30 minutes)
    - Add IR code validation before enabling auto mode
    - Add ESP-NOW packet size validation to prevent memory corruption
    Remote Sensor Fixes:
    - Add MAC address validation warning for default placeholder address
    - Add WiFi connection timeout (30 seconds) to prevent infinite loop
    - Add auto-restart on ESP-NOW init failure
    - Improve error messages for peer add failures
    These fixes address critical reliability and safe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
    [Arduino_TCM_Blynk_DHT11.ino, Remote_Sensor_ESP32.ino]
2025-11-22 Add 433MHz RF ceiling fan control for 3 independent fans
    Main Controller Updates:
    - Add RCSwitch library support for 433MHz RF transmission
    - Implement control for 3 ceiling fans (Off/Low/Med/High speeds + Light)
    - Add 16 new Blynk virtual pins (V16-V31) for fan controls
    - Implement RF learning mode to capture codes from fan remotes
    - Add RF code EEPROM storage (persistent across reboots)
    - Support configurable bit length for different RF protocols
    - Send each RF command 3 times for reliability
    Features:
    - Fan 1 Controls: V16 (Off), V17 (Low), V18 (Med), V19 (High), V20 (Light)
    - Fan 2 Controls: V21 (Off), V22 (Low), V23 (Med), V24 (High), V25 (Light)
    - Fan 3 Controls: V26 (Off), V27 (Low),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
    [Arduino_TCM_Blynk_DHT11.ino]
2025-11-23 Add temperature equalization learning system
    Implements machine learning to automatically balance temperatures across zones
    using ceiling fans. System learns which fan at which speed affects temperature
    in each zone, then uses this knowledge to intelligently equalize temperatures.
    Key Features:
    - Tracks fan state (speed 0-3) and operation duration
    - Learns temperature change rates (°F per minute) for each fan/speed combo
    - Stores up to 50 samples per configuration using running averages
    - Auto-equalization mode activates when zones differ by threshold (default 3°F)
    - EEPROM persistence preserves learned patterns across reboots
    - Requires minimum 2 minutes stable operation before learning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
    [Arduino_TCM_Blynk_DHT11.ino]
2025-11-26 Add ST7789 LCD display support with real-time dashboard
    Implements optional 135x240 ST7789 LCD display showing comprehensive
    system status in landscape mode (240x135 effective).
    Hardware Features:
    - SPI interface (GPIO18/23/5/2/0)
    - 135x240 pixel color display in landscape orientation
    - Auto-refresh every 2 seconds
    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
2025-11-26 Fix ESP-NOW callback for ESP32 Arduino Core 3.x compatibility
    Updates ESP-NOW receive callback signature to support newer ESP-IDF 5.x
    and ESP32 Arduino Core 3.x versions.
    - Updated onDataReceive() signature from old format:
    void onDataReceive(const uint8_t *mac, const uint8_t *data, int len)
    To new format:
    void onDataReceive(const esp_now_recv_info_t *recv_info, const uint8_t *data, int len)
    This fixes compilation error on ESP32 Arduino Core 3.x while maintaining
    backward compatibility with the ESP-NOW protocol.
    The MAC address (if needed) can be accessed via recv_info->src_addr.
    Current implementation doesn't use MAC address, so only signature changed.
    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
    [Arduino_TCM_Blynk_DHT11.ino]
2025-11-26 Revert ESP-NOW callback to ESP32 Core 2.x signature
    Reverts ESP-NOW callback signature back to Core 2.x format for
    compatibility with ESP32 Arduino Core 2.0.17.
    - Reverted from: esp_now_recv_info_t *recv_info (Core 3.x)
    - Back to: const uint8_t *mac (Core 2.x)
    This is needed because IRremoteESP8266 library requires Core 2.x
    for stable operation.
    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
    [Arduino_TCM_Blynk_DHT11.ino]
2025-11-26 Switch to Adafruit_ST7789 library and fix pin conflicts
    Major changes to support user's actual ST7789 display hardware:
    Library Changes:
    - Replaced TFT_eSPI with Adafruit_GFX + Adafruit_ST7789
    - Updated all color constants (TFT_* to ST77XX_*)
    - Changed display object from 'tft' to 'lcd'
    - Added backlight control on GPIO32
    Pin Reassignments (to avoid LCD conflicts):
    - LCD_CS: GPIO15 (as per user's display)
    - LCD_DC: GPIO2
    - LCD_RST: GPIO4 (as per user's display)
    - LCD_MOSI: GPIO23
    - LCD_SCLK: GPIO18
    - LCD_BLK: GPIO32 (backlight control)
    - DHT11: GPIO13 (moved from GPIO4 - conflicted with LCD_RST)
    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
    [Arduino_TCM_Blynk_DHT11.ino]
2025-11-26 Add large font rotating display pages for better visibility
    Completely redesigned LCD display for elderly users with vision issues:
    Display System:
    - 4 rotating pages, each displayed for 4 seconds
    - LARGE fonts (size 2-4) for easy reading
    - Color-coded status indicators
    - Simplified information per page
    Page 1: ZONE TEMPERATURES
    - Zone 1 temp (size 4 - HUGE)
    - Zone 2 temp (size 4 - HUGE)
    - Orange labels, white values
    Page 2: STOVE CONTROL
    - Target temperature (size 3 - BIG)
    - Heat level bars (size 3 - BIG with # symbols)
    - Stove ON/OFF status (size 3 - BIG)
    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
    [Arduino_TCM_Blynk_DHT11.ino]
2025-11-26 Implement 4-zone temperature monitoring system
    Major upgrade to support 4 independent temperature zones with zone-specific
    fan control and learning.
    System Architecture:
    - Zone 0: Main/Stove area (local DHT11 on main controller)
    - Zone 1: Fan 1 area (remote sensor #1)
    - Zone 2: Fan 2 area (remote sensor #2)
    - Zone 3: Fan 3 area (remote sensor #3)
    - Replaced single temp variables with zone arrays
    - zoneTemp[4]: Temperature for each zone
    - zoneHumidity[4]: Humidity for each zone
    - lastZoneTempTime[4]: Last update timestamp per zone
    - Zone 0 controls pellet stove (thermostat zone)
    - Receives ESP-NOW data from 3 remote sensors
    ESP-NOW Updates:
    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
    [Arduino_TCM_Blynk_DHT11.ino, Remote_Sensor_ESP32.ino]
2025-11-26 Fix compilation errors after 4-zone refactoring
    Fixed all variable reference errors from localTemp/remoteTemp → zoneTemp[] migration:
    Fixes in collectTemperatureSample():
    - lastRemoteTempTime → lastZoneTempTime[1]
    - localTemp → zoneTemp[0]
    - remoteTemp → zoneTemp[1]
    - Updated learning to use Zone 0 and Zone 1
    Fixes in autoEqualizeTemperatures():
    - lastRemoteTempTime → lastZoneTempTime[1]
    - localTemp → zoneTemp[0]
    - remoteTemp → zoneTemp[1]
    Fixes in BLYNK_WRITE(ZONE_SELECT_VPIN):
    - Added activeZone variable back for backward compatibility
    - Updated validation for 4 zones (0-3)
    - Updated zone names array
    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
    [Arduino_TCM_Blynk_DHT11.ino]
2025-11-26 Add comprehensive DHT11 sensor troubleshooting output
    Enhanced serial debugging for temperature sensor diagnostics:
    Serial Output Every 2 Minutes:
    - Shows DHT11 read attempt with clear headers
    - RAW values (humidity %, temp °C, converted °F)
    - Success/fail status with visual indicators
    - All 4 zones status with timestamps
    - Shows which zone is controlling thermostat
    - Complete stove status (ON/OFF, heat level, mode)
    If Sensor Fails:
    - Shows fail count (X/3)
    - Displays troubleshooting checklist:
    * Check GPIO13 connection
    * Verify VCC → 3.3V
    * Verify GND → GND
    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
    [Arduino_TCM_Blynk_DHT11.ino]
2025-11-26 Add serial command interface for troubleshooting
    Complete serial command-line interface for controlling system
    without Blynk. Perfect for testing and debugging.
    Available Commands:
    SENSOR:
    - TEMP: Force immediate temperature reading
    - ZONES: Show all 4 zone temperatures and status
    STOVE:
    - ON/OFF: Turn stove on/off
    - HEAT <1-5>: Set heat level (1-5)
    - AUTO/MANUAL: Toggle auto mode
    - TARGET <60-80>: Set target temperature
    FANS:
    - FAN1/FAN2/FAN3 OFF/LOW/MED/HIGH: Control individual fans
    - FANS OFF: Turn all fans off immediately
    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
    [Arduino_TCM_Blynk_DHT11.ino]
2025-11-26 Add missing adjustHeatLevel() function for serial commands
    - Implement adjustHeatLevel() to set stove to specific heat level (1-5)
    - Function adjusts heat step-by-step with delays between commands
    - Fixes compilation error in HEAT serial command handler
    - Supports both increasing and decreasing heat to reach target level
    [Arduino_TCM_Blynk_DHT11.ino]
2025-11-26 Implement Blynk rate limiting and add comprehensive dashboard guide
    Rate Limiting Implementation:
    - Add BLYNK_UPDATE_INTERVAL constant (5 minutes = 300,000 ms)
    - Add lastBlynkUpdate[] array to track last update time per zone
    - Modified ESP-NOW callback to rate limit remote zone updates
    - Changed main sensor timer from 2 minutes to 5 minutes
    - Reduces Blynk messages from ~10,000/day to ~600/day
    New Documentation (BLYNK_SETUP.md):
    - Complete virtual pin reference table (V0-V35)
    - Step-by-step widget configuration for all 4 tabs
    - Dashboard layout recommendations with energy costs
    - Message usage optimization details and calculations
    - Troubleshooting guide for common issues
    - Quick start chec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
    [Arduino_TCM_Blynk_DHT11.ino]
2026-09-25 docs(hardware): add A2 shared node schematic and assembly plan
    [tcm_node_rev_a_draft.kicad_sch]
